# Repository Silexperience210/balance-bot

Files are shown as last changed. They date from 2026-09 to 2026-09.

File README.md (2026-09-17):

<div align="center">

# ₿ B-bot — le robot qui tient debout, en forme de Bitcoin

**ESP32-S3 · deux roues Ø83 mm · servos 360° · écran-visage · châssis imprimé en PETG**







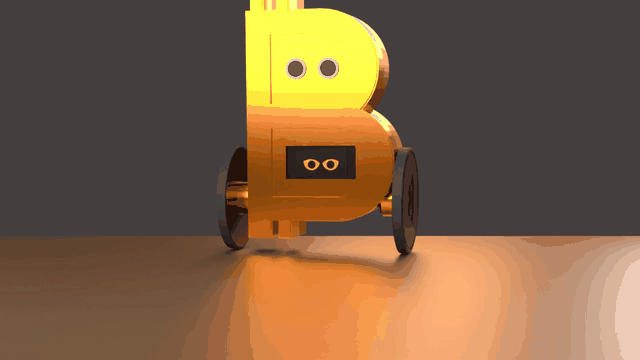
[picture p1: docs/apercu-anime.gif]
Aperçu du B-bot en mouvement


*Rendu du châssis réel — [voir la vidéo complète (26 s)](docs/video-rendu.mp4)*

### [▶ Essayer le simulateur maintenant](https://silexperience210.github.io/balance-bot/simulateur.html)

*Rien à installer : ça tourne dans le navigateur, avec les vrais fichiers STL du châssis.*

📖 **[Guide du simulateur](docs/GUIDE-SIMULATEUR.md)** — les commandes, les scénarios, le
capteur à ultrasons, et comment ajouter tes propres effets au robot (vent, pente, panne de
capteur, tape…).

</div>

---

## Le robot, en vrai

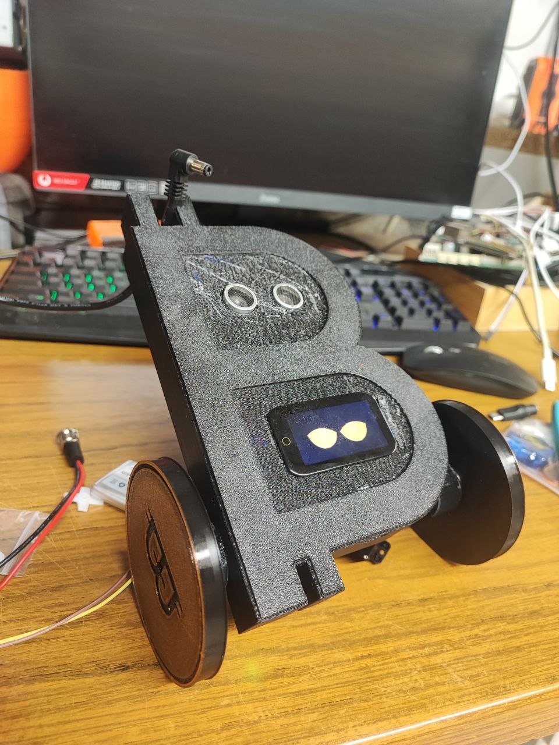
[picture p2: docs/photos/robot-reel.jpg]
Le prototype sur l'établi


Le prototype imprimé en PETG. Le corps **est** le glyphe ₿ ; l'écran couleur lui fait
un visage, les deux capteurs à ultrasons tiennent lieu d'yeux, et les roues sont
chaussées de bandes TPU imprimées.

## L'idée

Un robot auto-équilibré classique tient sur deux roues grâce à un asservissement :
il mesure son inclinaison deux cents fois par seconde et commande ses roues pour
ramener son centre de gravité sous lui, en permanence, y compris à l'arrêt. Ici,
cette mécanique éprouvée porte une coque dessinée comme le symbole Bitcoin, avec un
écran qui lui donne une tête.

Ce dépôt contient **le firmware, le châssis (CAO + STL) et un simulateur** — dont un
simulateur web qui rejoue la même physique que le robot, dans le navigateur.

## Ce qu'il fait

- **Il se tient debout tout seul** — boucle d'équilibre à **200 Hz**, correcteur PID
  sur l'angle du pendule inversé, avec recentrage pour ne pas dériver.
- **Il réagit à ce qu'il voit** — un HC-SR04 scrute devant lui (portée utile 150 cm,
  arrêt d'urgence à 25 cm).
- **Il a un visage** — l'écran ST7789 dessine des yeux dont l'expression suit l'état
  réel du robot (équilibre, chute, batterie faible).
- **Il se règle à chaud** — on se connecte au point d'accès **`BalanceBot-Tune`**
  (http://192.168.4.1/) et on ajuste les gains avec des curseurs, en regardant la
  télémétrie, **sans recompiler**.
- **Il surveille sa batterie** — tension mesurée en continu, seuil bas à 3,5 V (et
  distinction « batterie faible » / « alimenté par USB »).

## Le simulateur

C'est la pièce maîtresse pour qui veut toucher au contrôle sans risquer un robot.

- **`sim/balancebot_sim.py`** — le modèle Python : pendule inversé 1D, **le même
  correcteur que le firmware**, et deux modes physiques (`roue` pour les servos
  360°, `arc` pour l'ancienne mécanique à pieds).
- **`sim/web/`** — le simulateur navigateur : moteur JavaScript **vérifié numéro à
  numéro contre la version Python** (même générateur aléatoire, écart nul sur les
  scénarios sans bruit), rendu **Three.js avec les vrais STL du châssis**, l'écran et
  son visage, un banc de six scénarios et tous les gains réglables au curseur.

### La règle d'or

> **Le simulateur et le firmware doivent dire la même chose.**

Toute divergence entre les deux est traitée comme un bug **du simulateur comme du
firmware** : la physique (rayon de roue, hauteur du centre de gravité, signe des
termes de commande), les butées et les seuils sont alignés des deux côtés. C'est ce
qui permet de régler des gains en simulation avant de risquer le robot — le
simulateur a par exemple écarté un `Ki` vingt fois trop faible qui ne pouvait pas
tenir debout.

## Sous le capot

| Élément | Détail |
|---|---|
| Carte | LilyGo T-Display-S3-Touch (ESP32-S3R8, 16 Mo flash, 8 Mo PSRAM) |
| Capteur d'assiette | MPU6050 (I2C 400 kHz, filtre complémentaire) |
| Écran | ST7789 170×320 (paysage), dalle tactile CST816 |
| Distance | HC-SR04 (broche ECHO avec diviseur de tension) |
| Actionneurs | 2× servos 9 g **à rotation continue** pour les roues (sélecteur 180°/360° à la compilation) |
| Batterie | 1S LiPo, mesure par ADC, seuil bas 3,5 V |
| Boucles | équilibre **200 Hz**, interface 60 Hz, tête/ultrason 50 Hz |
| Châssis | ₿ 132 × 46 × 201 mm, ~378 g (367 g PETG + 11 g TPU), voie 108 mm |

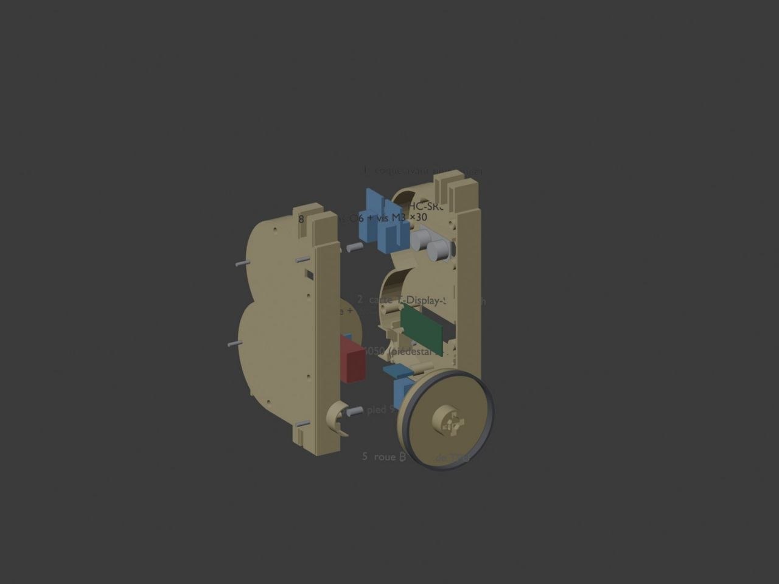
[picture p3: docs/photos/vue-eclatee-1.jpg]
Vue éclatée du châssis


## Physique et réglage

Le robot est un pendule inversé : rayon de roue **R = 41,5 mm** (pneu Ø83), hauteur
du centre de gravité **H = 80 mm**, gravité 9,81 m/s². Les gains embarqués sont
`Kp 25 · Ki 500 · Kd 0,5`, avec une condition de stabilité utile : **Ki > g/R ≈ 300**
(pour un robot d'environ 40 mm de rayon effectif, un terme intégral trop faible ne
rattrape jamais une inclinaison lente).

Le réglage fin se fait au banc web, sans recompiler.

## Le dépôt

```
balance-bot/          FIRMWARE (ce qui tourne sur la carte)
  balance-bot.ino     assemblage + cadences (200 / 60 / 50 Hz)
  config.h            affectations des broches — source unique
  interfaces.h        BotState partagé (contrat entre modules)
  imu.cpp/h           MPU6050, filtre complémentaire, détection de figement
  balance.cpp         correcteur d'équilibre + recentrage
  feet.cpp/h          actionneur des roues (position ou rotation continue)
  head.cpp            tête pan/tilt + télémétrie ultrason
  battery.cpp/h       mesure batterie, seuils, hystérésis
  ui.cpp              écran + écran-visage + boutons
  tuner.cpp/h         banc de réglage web à chaud (AP BalanceBot-Tune)
chassis/              CAO : gen_bitcoin_bot.py, STL (v3/), NOTES_v3.md, rendus
sim/                  simulateur Python (même correcteur que le firmware)
  web/                simulateur navigateur (Three.js + STL réels)
docs/                 visuels, vidéo de présentation et guide du simulateur
scripts/              vérificateur de la règle d'or (simulateur ↔ firmware)
ROADMAP.md            la feuille de route du projet, avec l'état de chaque chantier
TEST_PROTOCOL.md      protocole du premier essai debout (à lire avant d'allumer)
BACKLOG.md            suivi de la campagne d'amélioration
REVIEW_KIMI.md        revue de code indépendante (agent Kimi K3)
REVIEW_CLAUDE.md      contre-revue indépendante (agent Claude Opus)
```

## Méthode

Le firmware a été écrit et durci par **revues croisées d'agents** : une première
revue indépendante, puis une contre-revue chargée de contester la première — les
désaccords ont été tranchés en lisant le code, pas en votant. Elle a produit une
dizaine de corrections réelles (signe d'un terme de commande inversé entre le
simulateur et le firmware, butée logicielle inversée, zone morte qui transformait le
terme intégral en cliquet, garde batterie qui coupait en pleine action sur un seul
échantillon…). Les comptes rendus sont dans le dépôt, avec les correctifs.

## Avertissement

Projet personnel en cours de mise au point. Le firmware est fonctionnel et
compilable, mais les gains et la mécanique évoluent encore : lis `TEST_PROTOCOL.md`
avant la première mise sous tension, et ne pose jamais un robot équipé de servos sur
une table sans surveiller le premier essai.

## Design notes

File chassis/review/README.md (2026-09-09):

# chassis/review — audit & vérification du châssis ₿ BalanceBot v3.1

Outils d'analyse **mesurée** des STL (aucune confiance dans le générateur : on sonde les maillages).
Tous les scripts tournent avec le venv DfAM (`trimesh` + `scipy`) :

```bash
~/.hermes/venvs/dfam/bin/python chassis/review/<script>.py
```

| Fichier | Rôle |
|---|---|
| `RAPPORT_IMPRESSION_v31.md` | Revue d'impression complète (cotes, surplombs, anomalies, optimisations) — état AVANT corrections |
| `audit.py` | Audit topologique : bbox, volume, composantes, boucles ouvertes, non-manifold, surplombs par orientation d'impression |
| `verif_ultime.py` | **Vérification finale 25 points** : arêtes libres = 0, non-manifold = 0, cotes, volumes, paliers G+D, avant-trous M3, alésages goujons, yeux HC-SR04, fenêtre écran, roue, pneu |
| `test_ouverture.py` | Vérifie que les coques sont bien OUVERTES au joint (design CREUX) et non scellées par une peau |
| `faces.py` | Surplombs réels dans l'orientation d'impression : liste les plafonds plats par altitude (ponts vs support) |
| `find_transform.py` | Retrouve la transformation plaque↔pièce par alignement de sommets (sert à valider `chassis/make_plates.py`) |
| `diag_roue.py` | Diagnostic roue : sections, moyeu, jante, gorge de pneu |
| `mesures_baseline.json` | Mesures de référence du 09/09 (avant corrections) — sert de témoin de non-régression |

## Chaîne complète après un changement de châssis

```bash
blender --background --python chassis/gen_bitcoin_bot.py   # régénère chassis/v3/*.stl
python3 chassis/make_plates.py                             # régénère export/v31/*.stl
~/.hermes/venvs/dfam/bin/python chassis/review/verif_ultime.py   # doit afficher 25/25
```

## Repères (état vérifié 09/09/2026)

- b_front 132,13 × 23,02 × 201,00 — 105,8 cm³ (134 g PETG) — watertight, 5 composantes (1 coque + 4 vides d'avant-trous M3)
- b_back 132,13 × 29,00 × 201,00 — 91,5 cm³ (116 g PETG) — watertight, 1 composante
- coin_wheel Ø80 × 21 — 42,6 cm³ (54 g) · coin_tire Ø83 × 7 — 4,4 cm³ (5,6 g TPU)
- Surplombs réels : 6,7 k mm² (front, dont 5,8 k = fond des creux ₿), 1,05 k (back), 0,59 k (roue), 0 (pneu) → **zéro support**
- Réglages : coques 0,28 mm / roue 0,20 / pneu 0,24 · brim 5 mm · lit 70-80 °C · ponts 0,9 / 25 mm/s

## Pièges déjà payés (ne pas les réintroduire)

- **Outil de perçage coplanaire à une face** → voile/bouchon d'épaisseur nulle. Tout alésage doit DÉPASSER
  la face de sortie de 2 mm (c'est ce qui bouchait le palier gauche).
- **Composante reliée seulement par un sommet** = déchet, pas du solide : purger par connectivité d'ARÊTES.
- **Vide interne légitime** (avant-trou borgne) = composante fermée séparée : ce n'est PAS une pièce flottante.
- **Plaques de slicing périmées** : `make_plates.py` après chaque régénération, sinon on slice l'ancien design.
- **Sonder sur l'axe d'un palier donne un vide** (c'est normal) : sonder dans la paroi du tube (y = ±12,8).

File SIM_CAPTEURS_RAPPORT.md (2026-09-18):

# SIM_CAPTEURS_RAPPORT — Capteurs à ultrasons + animations du corps

Date : 2026-09-17. Portée : `sim/web/` + l'emballeur. Le firmware
(`balance-bot/`) et le châssis n'ont **pas** été touchés — ils restent la
référence. Le cœur du moteur `engine.js` n'a **pas** été modifié : le hook
`customEffects` reste la seule porte d'injection de la physique.

## Ce qui a été ajouté, fichier par fichier

### `sim/web/ultrason.js` (NOUVEAU)

Module pur JS (zéro dépendance, exporte `window.Ultrason` + `module.exports`
pour Node), transcription comportementale de `balance-bot/head.cpp`. Il est
cadencé sur l'horloge du moteur : le viewer l'appelle une fois par pas de 5 ms
(200 Hz = `BALANCE_LOOP_HZ`, `config.h:65`), donc les mesures tombent tous les
40 pas — tous les 200 pas après 3 échecs. Chaque comportement, ligne à ligne :

| Comportement simulé | Référence firmware |
|---|---|
| Constantes `US_MAX_CM = 150`, `US_STOP_CM = 25` | `config.h:75-76` |
| Bornes tête pan 0…180°, tilt 20…90°, centre 90°/60° | `config.h:71-74`, `head.cpp:59-62` |
| Vitesse tête 30°/s, position float bornée par pas | `head.cpp:38-39`, `head.cpp:191-195` |
| Cadence adaptative : 200 ms, 1000 ms après 3 échecs consécutifs, retour à 200 ms dès qu'un écho revient | `head.cpp:106-113` |
| Timeout `pulseIn` = `150 × 58 + 800 = 9500 µs` : l'écho « revient » si `dist × 58 ≤ 9500` (soit ≈ 163,8 cm) | `head.cpp:134-135` |
| Conversion `distance = durée_µs / 58` (côté sim : la distance réelle est l'entrée, la durée est le critère d'écho) | `head.cpp:139` |
| Timeout **non injecté** dans la moyenne, distance publiée −1, pas d'alerte | `head.cpp:146-151` |
| Lissage exponentiel sur 5 échantillons (`moy += (mesure − moy) / 5`), amorcé sur la 1re mesure | `head.cpp:26-28`, `head.cpp:155-157` |
| Alerte quand la distance lissée < 25 cm, angle où l'obstacle a été vu | `head.cpp:163-170` |
| Lissée > 150 cm → « hors portée » (`obstacleCm = −1`) **sans** compter un échec | `head.cpp:173-175` |
| Équilibre → tête ramenée au centre, immobile ; au sol → balayage continu | `head.cpp:190-205` |
| `reset()` = `Head::begin()` : lissage et balayage remis à zéro | `head.cpp:84-95` |

Le module ne fait que **publier** `obstacleCm` / `obstacleWarn` / `angleVu` :
comme le firmware, il ne déclenche aucune réaction physique du robot.

### `sim/web/ui.js` (modifié)

- **Garde-fou** : bannière d'erreur si `ultrason.js` est absent (même esprit que
  celui d'`engine.js`).
- **Module HC-SR04 en 3D** : pièce achetée, pas de STL → modélisation
  Three.js : PCB bleu 45 × 20 × 2 mm + deux transducteurs Ø16 × 12 mm avec
  grille avant. UN SEUL module, comme le robot réel (`config.h:61-62` :
  un TRIG, un ECHO ; `docs/photos/robot-reel.jpg`) : centré en Z sur la face
  avant, lobe haut du ₿ (y = +98 mm au-dessus de l'axe), plaqué sur la coque
  (x = 23 mm, face avant mesurée sur `parts.js`). Ajouté à `groupeCorps` →
  il suit exactement les transformations du corps.
- **Mesure analytique** : la distance est calculée depuis la pose PHYSIQUE
  (`sim.state` : x = R·(θ+φ) + SONDE_X·cos θ + SONDE_Y·sin θ), jamais depuis
  le maillage — les animations ne peuvent pas la toucher (voir
  « Après contre-vérification »).
- **Obstacle déplaçable** : plaque verticale de 10 × 140 × 100 mm posée au sol,
  placée par le curseur (5–200 cm). La distance mesurée est recalculée chaque
  frame **depuis la sonde** (`getWorldPosition`) jusqu'à la face avant de
  l'obstacle, dans le plan du sol — pas depuis le centre du robot. Quand le
  robot roule vers l'obstacle, la mesure diminue réellement.
- **Faisceau** : cône semi-transparent apex au capteur, longueur = distance
  réelle bornée à la portée ; vert = obstacle détecté, rouge = ALERTE < 25 cm,
  gris discret = rien/hors portée, masqué si le capteur est débranché.
- **Cadencement** : dans la boucle rAF, après `sim.stepMany(n)`, le viewer
  appelle `us.tickMany(n, distanceReelleCm(), !sim.state.fallen)` — le capteur
  partage l'horloge simulée (mesures aux mêmes instants que sur le robot).
  `us.reset()` est couplé au bouton RESET et au changement de scénario.
- **Télémétrie capteur** : distance lissée, état (rien / obstacle /
  ALERTE < 25 cm / absent), cadence courante (200/1000 ms), échecs consécutifs,
  pan/tilt de la tête, angle vu.
- **Animations** (sélecteur « ANIMATIONS » + bouton « Rejouer ») : `Aucune`,
  `Hochement`, `Regard gauche-droite`, `Sursaut`, `Danse`. Couche strictement
  cosmétique : offsets (tangage, lacet, rebond) ajoutés au **maillage** après
  la pose physique dans `majScene()`, plus expression/regard du visage forcés
  (`visage.exprAnim` / `gazeAnim`). `sim.state` et la commande ne sont jamais
  touchés ; `Aucune` = offsets nuls → image strictement identique à avant.
  Horloge = temps réel rAF (l'animation joue même en pause, sans avancer la
  physique) ; `Sursaut` est un one-shot de 0,7 s relançable, les autres
  bouclent ; changer de sélection ou cliquer « Rejouer » repart de t = 0.

### `sim/web/index.html` (modifié)

- Deux panneaux dans la colonne de droite (style existant conservé) :
  « Capteur ultrason (HC-SR04) » (curseur d'obstacle 5–200 cm, case « ECHO
  câblé », mini-grille de télémétrie) et « Animations » (sélecteur + Rejouer).
- Balise `<script src="ultrason.js"></script>` entre `engine.js` et `parts.js`.
- Styles : `#sel-anim` repris du sélecteur de visage, états du capteur
  colorés via les variables du thème (`--vert`, `--rouge`).

### `sim/web/selfcheck.js` (modifié) + `sim/web/selfcheck.html` (modifié)

- Sections 1–4 **inchangées** (mêmes valeurs de référence Python, mêmes
  tolérances) — la physique n'a pas bougé et l'écart reste nul.
- Nouvelle section 5 (16 contrôles) sur `ultrason.js` : cadence 200 ms
  (mesures à 200/400/600/800/1000 ms), amorçage du lissage, saut 80→30 cm
  (moy = 70 exactement), convergence, cadence 1000 ms après 3 échecs
  (200/400/600/1600/2600 ms), retour à 200 ms à l'écho retrouvé, timeout non
  injecté (44 = 40 + (60−40)/5), portée (160 cm = écho hors portée sans échec,
  170 cm = timeout), alerte < 25 cm + angle vu = 90°, balayage borné 0…180°,
  recentrage 90°/60° en équilibre.
- `selfcheck.html` charge `ultrason.js` avant `selfcheck.js`.

### `chassis/assets/emballer_simulateur.py` (modifié)

`ultrason.js` ajouté à `ORDRE`. Régénéré : `sim/web/simulateur-balancebot.html`
(1 424 548 octets, 6 fichiers inlinés, aucun `<script src=` résiduel) puis
copié sur `simulateur.html` à la racine (la racine était une copie exacte du
bundle, vérifié par `cmp` avant régénération). Vérifié en `file://` sous
Chrome headless : la scène rend, l'auto-test passe dans le navigateur.

## Sortie réelle de `node sim/web/selfcheck.js`

```
BalanceBot — auto-test du moteur engine.js

1. PRNG MT19937 + random.gauss (référence : CPython, random.seed(42))
  ✔ random() → 0.6394267984578837, 0.025010755222666936
  ✔ gauss(0,1) → -0.14409032957792836, -0.1729036003315193

2. Gains embarqués Kp25/Ki500/Kd0.5, k_out=1, kv=3, cascade ON, graine 42
    θ0=2° propre    : ❌ chute θ  t=0.545 s  θfin=+45.920°  φfin=+23.445°   = Python
    θ0=2° bruit     : ❌ chute θ  t=0.545 s  θfin=+45.919°  φfin=+23.603°   = Python
    θ0=5° bruit     : ❌ chute θ  t=0.425 s  θfin=+46.609°  φfin=+25.944°   = Python
    tape 0.4 rad/s  : ❌ chute θ  t=0.485 s  θfin=+45.009°  φfin=+22.888°   = Python
    tape 0.8 rad/s  : ❌ chute θ  t=0.490 s  θfin=+46.071°  φfin=+24.034°   = Python
    tape 1.2 rad/s  : ❌ chute θ  t=0.485 s  θfin=+45.347°  φfin=+22.690°   = Python
  ✔ 0/6 scénarios tenus (obtenu 0/6)
  ✔ verdicts, instants et états finaux conformes au Python

3. Kp25/Ki350/Kd1, k_out=3, kv=0, cascade ON, graine 42
  ✔ θ0=2° propre → « ok », θ fin = +0.0000° (< 0,5°), φ fin = +7.96°
    θ0=2° propre    : OK         t=5.995 s  θfin=+0.000°  φfin=+7.959°   = Python
    θ0=2° bruit     : OK         t=5.995 s  θfin=-0.038°  φfin=-2.602°   = Python
    θ0=5° bruit     : OK         t=5.995 s  θfin=-0.071°  φfin=+174.429°   = Python
    tape 0.4 rad/s  : OK         t=7.995 s  θfin=+0.001°  φfin=+423.887°   = Python
    tape 0.8 rad/s  : OK         t=7.995 s  θfin=+0.076°  φfin=+829.829°   = Python
    tape 1.2 rad/s  : ❌ chute θ  t=3.585 s  θfin=+45.704°  φfin=+152.366°   = Python
  ✔ 5/6 scénarios tenus comme le Python (obtenu 5/6)
  ✔ verdicts, instants et états finaux conformes au Python

4. Hook setCustom(fn) : appelé après la physique, une fois par pas
  ✔ 100 pas → 100 appels, t = 0.495 s, dt = 0.005
  ✔ state.theta = 60° écrit par le hook à t = 1 s → « chute θ » au même pas

5. Capteur HC-SR04 (ultrason.js) — cadence, lissage, portée, alerte, tête
  ✔ cadence 200 ms : mesures à 200, 400, 600, 800, 1000 ms
  ✔ lissage amorcé sur la 1re mesure : obstacleCm = 80 cm exactement
  ✔ saut 80→30 cm : une mesure après, moy = 70.00 (attendu 70)
  ✔ la moyenne glissante converge vers la distance réelle (30.000571 → 30, ±0,01 cm)
  ✔ capteur débranché : cadence 1000 ms après 3 échecs (200, 400, 600, 1600, 2600 ms)
  ✔ débranché : cadence affichée 1000 ms, distance invalide, pas d'alerte
  ✔ écho de retour → cadence 200 ms immédiate, moyenne re-amorcée à 50
  ✔ timeout : distance invalide publiée, pas d'alerte
  ✔ timeout non injecté : moyenne reprise en l'état (44.00 = 40 + (60−40)/5)
  ✔ 160 cm : écho reçu mais hors portée (obstacleCm = −1, pas d'échec)
  ✔ 170 cm : au-delà du timeout pulseIn (9860 > 9500 µs) → échec compté
  ✔ 20 cm lissés → ALERTE, angle vu = pan 90° (tête centrée)
  ✔ obstacle reparti → alerte et angle effacés
  ✔ balayage hors équilibre : pan borné à 0…180° (vu 0…180)
  ✔ équilibre : tête ramenée au centre (90°/60°) et immobile

═══ AUTO-TEST RÉUSSI ═══
```

(code de sortie 0 ; même verdict « AUTO-TEST RÉUSSI » sous Chrome headless en
ouvrant `sim/web/selfcheck.html` en `file://`.)

## Ce qui reste imparfait

- **Le balayage de tête n'est pas visible en 3D** : le châssis n'a pas de
  maillage de tête séparé (la « tête » est le corps entier), donc pan/tilt ne
  sont simulés que logiquement — affichés dans la télémétrie et utilisés pour
  l'« angle vu ». Faire pivoter le corps entier serait faux physiquement.
- **Après la chute, le temps simulé s'arrête** (le moteur s'arrête au verdict,
  comportement d'origine inchangé) : le balayage « robot au sol » n'est donc
  observable en pratique que dans l'auto-test, pas dans la scène live.
- **Distance mesurée dans le plan du sol** (distance horizontale sonde → face
  avant de l'obstacle) : on ignore la différence de hauteur, légitime pour un
  obstacle vertical, mais un obstacle très bas ou très haut ne serait pas
  distingué. L'obstacle est unique, vertical, et ne peut pas être déplacé
  latéralement (curseur de distance uniquement, pas de glisser 3D).
- **La distance est figée pendant chaque lot** de pas calculés entre deux
  frames (échantillonnée une fois par frame) : invisible, car le capteur
  n'échantillonne qu'au plus tous les 40 pas (200 ms).
- **Un seul capteur, logique ET visuel** (comme le firmware et le robot
  réel, `config.h:61-62` + photo) : un seul module HC-SR04 modélisé, la
  mesure part de la face avant de ses transducteurs.
- Le blocage de `pulseIn` (jusqu'à 9,5 ms volés à la boucle d'équilibre) n'est
  **pas** répercuté sur la physique — ce serait modifier le moteur, interdit
  par la mission ; seule la cadence des mesures est reproduite.

## Fichiers modifiés

- `sim/web/ultrason.js` — **nouveau** (capteur HC-SR04 + tête, miroir de `head.cpp`)
- `sim/web/ui.js` — module 3D, mesure analytique, faisceau, obstacle, animations, télémétrie capteur
- `sim/web/index.html` — panneaux « Capteur ultrason » et « Animations », script `ultrason.js`
- `sim/web/selfcheck.js` — section 5 (16 contrôles ultrason/tête), sections 1–4 inchangées
- `sim/web/selfcheck.html` — chargement d'`ultrason.js`
- `chassis/assets/emballer_simulateur.py` — `ultrason.js` ajouté à l'ordre d'inlining
- `sim/web/simulateur-balancebot.html` — régénéré (bundle mono-fichier)
- `simulateur.html` (racine) — copie du bundle régénéré

---

## Après contre-vérification (rapport indépendant `/home/silex/REVIEW_SIM_CAPTEURS.md`, HEAD `4796227`)

La contre-vérification a validé l'essentiel et relevé un défaut bloquant
(point C : les animations faussaient la mesure) plus des finitions. Tous les
points sont traités, dans `sim/web/` + `docs/GUIDE-SIMULATEUR.md` uniquement ;
`engine.js` et la physique d'`ultrason.js` n'ont pas bougé (seul le critère
d'écho du point F-b est corrigé, voir ci-dessous).

**1. (BLOQUANT, défaut C) La distance ne dépend plus des animations.**
Avant : la sonde était un `Object3D` enfant de `groupeCorps`, donc
`distanceReelleCm()` (via `getWorldPosition()`) incluait les offsets
d'animation appliqués par `majScene()`. Correction choisie : la distance est
calculée **analytiquement depuis la pose physique** (`sim.state`), sans passer
par la scène :

```
x_sonde = R·(θ+φ) + SONDE_X·cos θ + SONDE_Y·sin θ     (z = 0)
```

C'est la garantie la plus forte : les offsets d'animation n'existant que dans
le maillage, une mesure qui ne lit pas le maillage ne peut pas les voir — par
construction, pas par convention. Le **faisceau reste enfant de
`groupeCorps`** (il suit visuellement le corps, animations comprises : c'est
le choix assumé, il n'est qu'un pointeur), mais sa **longueur** vient de la
distance physique. Vérifié **par la mesure** (banc Node/Playwright dans
`/tmp/bench`, Chrome, même méthode que le rapport — pause, curseur 18 cm,
θ = 2°) :

| | anim « aucune » | hochement | regard | sursaut | danse |
|---|---|---|---|---|---|
| **avant** (HEAD) | 13,215 cm | 12,56–13,90 (Δ 1,34) | 13,22–13,42 (Δ 0,21) | 13,22–14,07 (Δ 0,86) | 12,87–13,88 (Δ 1,01) |
| **après** | 13,215 cm | **13,215 cm fixe (Δ 0,000)** | idem | idem | idem |

En RUN (« θ0=2° propre », curseur 18 cm) : lissée 13,126 cm sans animation ;
après 3 s de « danse » : **13,124 cm** après correction (13,281 cm avant,
fluctuante). La valeur de référence 13,215 cm est strictement identique avant
et après : la formule analytique retombe sur la pose monde mesurée (sonde
x = 42,85 mm).

**2. (BLOQUANT, F-5) Un seul module HC-SR04.** Le robot réel n'a qu'un module
(`config.h:61-62` ; sur la photo ce sont ses deux transducteurs qui font les
« yeux »). La scène 3D n'en modélise plus qu'**un**, centré en Z (z = 0) à la
place des yeux de la photo : face avant x = 23 mm, lobe haut y = +98 mm,
au-dessus de l'écran. Logique inchangée (un seul capteur, comme le firmware).

**3. (E) Panneau « Obstacle » clarifié.** Ajout d'une ligne d'aide dans le
panneau : le curseur place le **centre d'une plaque de 10 mm mesuré depuis
l'axe des roues au RESET** (si le robot roule, la mesure s'en écarte), et en
**PAUSE** la télémétrie est figée (le capteur ne tique qu'en marche) alors que
le faisceau suit le curseur.

**4. (F-b) Seuil d'écho réel ≈ 155 cm — reproduit, pas seulement documenté.**
Dans le core ESP32, le timeout de `pulseIn` court depuis l'appel, attente du
front montant d'ECHO incluse (~450–500 µs après TRIG — à quoi sert la marge
de 800 µs du firmware). `ultrason.js` modélise désormais ce délai
(`ECHO_DELAI_FRONT_US = 480`, milieu de la plage) : l'écho revient si
`dist×58 + 480 ≤ 9500 µs`, soit un seuil à **155,5 cm** comme le vrai robot.
Le selfcheck borne le seuil : 155 cm = écho hors portée sans échec, 156 cm =
échec compté.

**5. (F-f) Trous de l'auto-test comblés** (section 5 : 16 → 20 contrôles) :
vitesse de pan mesurée (90 → 120° en 1 s de balayage), vitesse de tilt
(60 → 75° en 0,5 s), bornes du tilt en balayage (20…90°), `angleVu` testé à
un pan ≠ 90° (alerte pendant le balayage → 96°, pas le centre). Contre-épreuve
par mutation : `PAN_SPEED 30→60` ✘ détecté (2 contrôles), `HEAD_TILT_MIN 20→0`
✘ détecté, `ECHO_DELAI_FRONT_US 480→0` ✘ détecté.

**6. Libellé** : « moyenne re-amorcée à 50 » → « moyenne amorcée à 50 (premier
écho reçu) » — le capteur n'avait jamais reçu d'écho dans ce scénario.

**7. Commentaire du faisceau** : le « demi-angle ~7° » était faux
(`ConeGeometry(0.0122, 1)` = 0,7° à 1 m, et seul `scale.x` varie). Le
commentaire dit désormais la vérité : rayon constant 12,2 mm, demi-angle
apparent dépendant de la longueur — un pointeur visuel, pas le lobe réel
(~15°) du HC-SR04.

**8. Pas de collision** : écrit dans `docs/GUIDE-SIMULATEUR.md` §8 (« Ce que le
simulateur ne fait pas ») — le robot peut traverser l'obstacle, comme le
firmware qui ne réagit pas.

**Validation finale** : bundle régénéré (`emballer_simulateur.py` →
`sim/web/simulateur-balancebot.html`, 1 426 820 octets, 6 fichiers inlinés,
0 `<script src=` résiduel) et copié sur `simulateur.html` à la racine
(`cmp` identique). `node sim/web/selfcheck.js` → exit 0, sections 1–4
inchangées, section 5 (extraits) :

```
  ✔ 155 cm : écho reçu mais hors portée (obstacleCm = −1, pas d'échec)
  ✔ 156 cm : au-delà du seuil réel (9528 > 9500 µs) → échec compté
  ✔ 170 cm : au-delà du timeout pulseIn (10340 > 9500 µs) → échec compté
  ✔ balayage hors équilibre : tilt borné à 20…90° (vu 20…90)
  ✔ vitesse de pan 30°/s : 90 → 120° après 1 s de balayage (attendu 120)
  ✔ vitesse de tilt 30°/s : 60 → 75° après 0,5 s de balayage (attendu 75)
  ✔ alerte pendant le balayage : angle vu = pan courant (96°, ≠ 90°)
═══ AUTO-TEST RÉUSSI ═══
```

(même verdict « AUTO-TEST RÉUSSI » sous Chrome headless en `file://` ; rendu
du bundle vérifié par capture : un seul module à deux transducteurs au-dessus
de l'écran, comme la photo.)

---

**Post-scriptum (miroir du firmware `10044c0`, 18/09/2026)** — ce rapport décrit l'état
au commit `2911095` : les numéros de lignes de `head.cpp` cités ci-dessus sont ceux d'AVANT
`10044c0` (décalés d'environ +100 depuis : `kEchoTimeoutUs` l.134 → 232, cadence l.108 →
203, `handleHeadMovement` l.181-217 → 284-333), et les deux phrases « équilibre → tête
ramenée au centre, immobile » et « comme le firmware, il ne déclenche aucune réaction
physique » ne sont plus vraies : la tête balaie ±30° en équilibre et le firmware évite
l'obstacle (ralenti / recul + pivot / reprise). Le simulateur en est le miroir — voir
`SIM_MIROIR_RAPPORT.md`, `docs/GUIDE-SIMULATEUR.md` §5 bis et `sim/web/selfcheck.js` §6-8.

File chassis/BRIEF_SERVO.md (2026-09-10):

# Brief — Baies de servo du châssis BalanceBot v3 (à corriger)

## Contexte
Le châssis est **généré paramétriquement** par `chassis/gen_bitcoin_bot.py`
(script Blender). Ne modifie QUE ce fichier et les STL régénérés.

Les 2 servos de roue sont des **SG90** : corps 22,8 × 12,2 × 22,5, **arbre de
sortie à 5,9 mm du fond** du corps, bossage de sortie Ø11,8 × 1,5, **oreilles de
fixation 32,2 de long**, sortie de câble sur un flanc, et de petits **taquets de
moulage** en saillie.

Constantes du générateur (déjà dans le fichier) :
`SV_L=22.8`, `SV_W=12.2`, `SV_H=22.5`, `SV_SHAFT_OFF=5.9`, `SV_BOSS_D=11.8`,
`SV_BOSS_H=1.5`, `SV_PILOT_D`, `HUB_BORE_D=SV_SHAFT_D+0.4`, `WALL=2.4`,
`AXLE_Z=42.0`, `GW=118`.

Implantation prévue par le code (repère NON miroir) :
- servo couché, **axe selon X**, sortant par les parois latérales à `z = AXLE_Z` ;
- corps entre `z = AXLE_Z - SV_SHAFT_OFF` et `z + SV_L` (soit 36,1 → 58,9) ;
- cavité ouverte depuis `x = WALL` (côté spine) et depuis
  `x = x_wall_R - WALL` (côté paroi courbe), corps s'étendant vers l'intérieur ;
- l'arbre + le bossage traversent la paroi par un trou Ø12,8 (`axR`/`axL`) et
  entrent dans le **moyeu Ø24 de la roue** ; le moyeu tourne dans le
  **tube-palier Ø24,5** extérieur ;
- les oreilles se vissent (M2 × 8, avant-trous Ø1,7) sur les **cloisons
  verticales (bulk) — cloisons à x = 12…23 et 68…79** (repère non miroir).

## Problème constaté sur la pièce réellement imprimée
1. **Le servo ne rentre pas.** Il possède un **taquet** (saillie de moulage) et
   ses oreilles de fixation ; la cavité est au plus juste → il faut **~1 mm de
   jeu en plus** sur les faces concernées.
2. **Côté opposé, un PLOT DE FIXATION tombe en plein milieu de l'emplacement du
   servo** et le bloque. (Vérifier aussi la cloison `bulk` : une cloison de 11 mm
   d'épaisseur tombe dans l'emprise du corps du servo.)

## Travail demandé

### 1. Trouver un VRAI modèle de SG90
Télécharge un modèle **STL ou STEP d'un SG90 réel** (GrabCAD, Printables,
Thingiverse, ou un dépôt de modèles CAO fiable). Vérifie sa provenance et que
ses cotes correspondent : corps 22,8 × 12,2 × 22,5, oreilles 32,2 × 12,2,
bossage Ø~11,8, arbre Ø4,8, **taquets et sortie de câble présents**. Si aucun
modèle correct n'existe, reconstruis un solide fidèle à partir d'un **datasheet
officiel** (TowerPro SG90 : drawing coté) et dis-le explicitement dans le
rapport.

### 2. Vérifier l'emplacement par la géométrie (pas à l'œil)
Dans Blender (headless) : importe les coques `b_front`/`b_back` régénérées et le
modèle de servo, place le servo **exactement** comme le prévoit le générateur,
puis mesure l'**intersection booléenne** servo × coques. Elle doit être **0 mm³**.
Liste chaque zone de collision avec ses cotes (x, y, z) et l'épaisseur à
enlever. Vérifie aussi qu'il reste **~1 mm de jeu** partout et qu'un **doigt de
montage** peut atteindre les oreilles.

### 3. Corriger `build_body()`
- élargir la cavité d'**au moins 1 mm** là où le taquet/les oreilles coincent ;
- **supprimer ou déplacer** le plot de fixation qui tombe dans l'emprise du servo
  (s'il sert à visser autre chose, déplace-le hors de l'emprise, ne le supprime
  pas à l'aveugle) ;
- dégager la sortie du câble et l'accès aux vis d'oreilles ;
- **NE PAS** toucher à l'enveloppe extérieure, à `AXLE_Z`, aux trous Ø12,8, aux
  tubes-paliers Ø24,5, ni à la poche de la carte / la fenêtre de la dalle.

### 4. Régénérer et prouver
- régénère les STL (comme `chassis/run_v3_design.sh` le fait) ;
- `python3 chassis/verif_ultime.py` doit rester **25/25** (watertight, 0 arête
  libre, 0 non-manifold, cotes de l'enveloppe inchangées) ;
- intersection servo/coques = **0 mm³** (re-mesure après correction) ;
- pas de nouveau surplomb critique pour l'impression.

### 5. Rapport final (court, chiffré)
Avant/après : cotes de la cavité modifiée, zone du plot déplacé, volume
d'intersection (avant → après), source et cotes du modèle de servo utilisé,
résultat de `verif_ultime.py`. Signale tout ce que tu n'as pas pu vérifier.

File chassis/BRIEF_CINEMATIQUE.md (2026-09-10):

# Brief — Cinématique BalanceBot : tout disparaît pendant l'éclaté

## Symptôme (constaté par l'utilisateur, confirmé par mesure)
Dans `chassis/render/cinematique.mp4`, **au moment de la vue éclatée, plus rien
n'est visible** : le cadre est vide et les pièces ont disparu. Le reste de la
vidéo est bon.

Mesures sur les images rendues (`chassis/render/frames/f_%04d.png`, 1280×720),
comptage des pixels « orange métal » (r>90, r>1.5g, g>1.3b) :

| image | phase | pixels orange | image occupée |
|---|---|---|---|
| 300 | orbite (OK) | 30 339 (x 468..807) | normal |
| 390 | début éclaté | 917 (x 303..363) | ça rétrécit |
| **421** | **pic de l'éclaté** | **333 (x 287..303, y 691..719)** | **1,6 % — cadre vide à 95-98 %** |
| 480 | remontage | 8 599 (x 378..467) | ça revient |

À l'image 420, un modèle de vision ne voit qu'**un petit objet cylindrique noir
(<1 % de l'image)**, décentré en bas à droite. Les coques orange (132 × 201 mm)
devraient pourtant occuper ~13 % du cadre à 1 000 mm avec l'objectif de 62 mm :
elles ne sont plus dans le champ.

## Code concerné (`chassis/assets/cinematique.py`)
- **Caméra** : bloc `CAM_KEYS` (à partir de « caméra : gros plan sur l'écran »).
  L'azimut vient de la rotation Z de l'empty `orbite` ; `placer_camera(0, dist,
  haut, cible)` ne pose que la position LOCALE et la visée.
- **Éclatement** : dict `ECLATE` + la boucle
  `pieces = {... if o.name in ECLATE}` → clés `(1, pos_a)`, `(240, pos_a)`,
  `(420, pos_e)`, `(570, pos_a)`.
- Les pièces éclatées sont parentées au `pivot` (empty sur l'axe des roues) avec
  `matrix_parent_inverse`.

## Suspicions à vérifier (ne pas se contenter de la première)
1. **La ROTATION de la caméra n'est jamais keyframée** — seule `location` l'est.
   La visée reste donc celle de la DERNIÈRE entrée de `CAM_KEYS` (image 780 :
   200 mm, haut 84, cible 76) alors que la caméra se balade de 115 à 1120 mm.
   Calcule l'écart de visée réel et son effet.
2. Interpolation Bézier des positions : vérifier qu'aucune clé n'overshoot (la
   caméra pourrait partir très loin entre deux clés).
3. Les vecteurs d'éclatement sont additionnés à `obj.location` : pour les coques
   importées (STL) `location` vaut (0,0,0) et la géométrie porte les cotes —
   vérifier que le décalage appliqué est bien celui attendu.
4. Vérifier enfin que rien ne masque : ordre le long de l'axe de visée.

## Travail demandé
1. **Diagnostiquer la cause RÉELLE** avec un **script de projection** :
   `bpy_extras.object_utils.world_to_camera_view` + `scene.frame_set(f)` **puis
   `bpy.context.view_layer.update()`** (sans ce refresh les matrices restent
   figées et la mesure est fausse — piège déjà rencontré). ATTENTION : les clés
   de caméra sont dans le bloc « mode cinématique », APRÈS la ligne
   `if MODE == "still":` → un probe qui n'exécute que l'en-tête du script n'aura
   AUCUNE animation de caméra. Construis le probe de façon à évaluer la scène
   animée complète.
   Pour chaque pièce et chaque image clé (300 / 390 / 420 / 480 / 570), imprime
   la position caméra monde, la boîte englobante en pixels et si elle est dans le
   cadre (0..1280 × 0..720).
2. **Corriger** ce qui est faux (viser correctement à chaque image — keyframer la
   visée si nécessaire — et adapter les distances/offsets pour que TOUTES les
   pièces restent dans le cadre avec une taille lisible pendant l'éclaté).
3. **Prouver** : re-rendre SEULEMENT quelques images de contrôle, pas les 780 :
   `blender --background --python chassis/assets/cinematique.py -- cine 390 430`
   (le script accepte déjà une plage `[début fin]`). Puis, sur ces images,
   **recompter les pixels orange** et vérifier que les coques ET les composants
   (carte, dalle, servos, capteurs) sont visibles et bien cadrés. Donne les
   chiffres avant/après.
4. Ne pas toucher : durée (26 s), 30 fps, 780 images, 1280×720, ni le châssis
   (`chassis/gen_bitcoin_bot.py`, les STL, le travail servos déjà commité).

## Rapport attendu
Cause racine (une phrase), ce qui a été changé (chiffres), les mesures de pixels
avant/après sur les images de contrôle, et ce que tu n'as PAS pu vérifier.

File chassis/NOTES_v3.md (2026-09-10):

# ₿ BalanceBot v3 — NOTES DE CONCEPTION (châssis symbole Bitcoin)

## Pièces (dans chassis/v3/) — cotes MESURÉES (09/09/2026)
| Fichier | Rôle | Dimensions (bbox mm) | Masse PETG (100 %) |
|---|---|---|---|
| b_front.stl | Coque avant (face ₿, écran, yeux) | 132,1 × 23,0 × 201,0 | 134 g |
| b_back.stl | Coque arrière (élec., goujons) | 132,1 × 29,0 × 201,0 | 116 g |
| coin_wheel.stl ×2 | Roues-pièces ₿ Ø80 × 10 + moyeu Ø24×13 | Ø80 × 21 | 54 g |
| coin_tire.stl ×2 | Bandes TPU (TPU 95A) | Ø83 × 7 | 5,6 g TPU |

Total ≈ 378 g (367 g PETG + 11 g TPU). Corps : glyphe ₿ 118 × 165 (GW × GH) + barres → 201 de haut,
profondeur 46 (23 + 23) + goujons 6. Voie des roues (plans médians) : ≈ 108 mm.
**Coques CREUSES** (pas de peau au joint) : la cavité s'ouvre sur le plan de joint y=0, le hardware
se monte par l'ouverture avant vissage (4 goujons + 4 vis M3).

## Montage
1. Servos 9 g continus (SG90-FS90R size) TÊTE EN BAS, collés à leur paroi : face de sortie contre la paroi
   latérale intérieure (gauche : spine x=90 ; droite : paroi courbe x≈11), corps dans la cavité, pattes
   vissées (M2 × 8, Ø1.7) sur les cloisons verticales (bulk) — cloisons à x = 12…23 et 68…79.
2. L'axe/bossage du servo traverse la paroi par un trou Ø12.8 (axR/axL) puis entre dans le moyeu Ø24 de la roue.
3. Roue : enfiler le moyeu sur le palonnier (croix) pré-vissé à l'axe ; le moyeu (13 mm) coulisse dans le
   tube-palier du corps (Ø24.5) ; l'empreinte au fond du moyeu (3.6 mm) attrape la croix. Jeu axial ~3 mm
   (lamage HUB_CB_H+3) pour ne pas serrer.
4. Bande TPU : étirer par-dessus la jante (gorge Ø69 × 8.4, bande Ø int 68.1 → interférence 0.9).
5. Joint des coques : goujons Ø5.8 (b_back, x4) → alésages Ø6.0 (b_front, prof 6.8) ; vis M3 × 30
   tête noyée Ø6.4 (b_back) → passage Ø3.4 → avant-trou Ø2.6 dans les plots du front (autotaraudage).
   Plots de vis à 4 endroits : spine z≈71/142, mur courbe bas droite (45°), plafond panse haute (z≈184).
6. Carte T-Display S3 : paysage, dalle dans la fenêtre 56 × 26 du contre-poinçon bas (lcz≈72 ; demande
   utilisateur du 10/09 : l'ouverture de 40,6 × 22,6 ne laissait pas passer la dalle + son encadrement) ;
   rails haut/bas + 2 vis M2 aux trous réels (x = lcx − 30.39 + 57.66, z = lcz ± 10) ; USB-C vers le bas
   (lumière sous le corps à z=19-23).
7. MPU6050 : piédestal dont le DESSUS est à z = 36.5 (l'axe de tangage !) ; vis M2 entraxe 15 (Ø1.7).
8. HC-SR04 : poussé dans la baie haute (fenêtre 45×20), transducteurs dans les 2 trous Ø16.6 (entraxe 26) ;
   colle sur les rails.
9. Interrupteur : lumière 13 × 8 côté arrière du spine (z 148-156).

## Orientation d'impression (P1S, plateau 256 × 256)
- b_front / b_back : face externe sur le plateau (creux vers le haut). Le creux COUNTER de la face ₿
  n'est PAS imprimé en l'air (la face externe EST le plateau) ; les 2 panse-creux (5 831 mm² à 1,6 mm)
  se pontent. Goujons/plots vers le haut. Hauteur d'impression 23 (front) / 29 (back) → ça rentre large.
- coin_wheel : face externe (₿ gravé) sur le plateau → la gravure sort en relief (creux du moule) ;
  moyeu vers le haut. PETG.
- coin_tire : à plat (anneau). TPU 95A.
- **Plaques de slicing** : `export/v31/plate1_b_front.stl` (201 × 132 au sol), `plate2_b_back.stl`,
  `plateR_wheel1/2.stl`, `plateT_tire1/2.stl`. **À RÉGÉNÉRER après tout changement** :
  `python3 chassis/make_plates.py` (transformations vérifiées : 100 % des sommets alignés).
  Les plaques de 14h44 du 08/09 étaient périmées (version FERMÉE + alésage de palier bouché).
- Le CLI headless refuse les coques > ~195 mm (dimension 201) → **slicer en GUI Bambu Studio**.

## Réglages de slicing recommandés (P1S, PETG 0,4 mm)
| Réglage | Coques (front/back) | Roue | Pneu |
|---|---|---|---|
| Hauteur de couche | **0,28** (−30 % de temps) | 0,20 (gravure ₿) | 0,24 |
| Parois | 6 (épaisseur 2,4 mm = la pièce) | 4 | 3 |
| Remplissage | n/a (parois pleines) | 20 % gyroid | 15 % gyroid |
| Support | **aucun** (ponts internes) | aucun | aucun |
| Adhérence | bordure (brim) 5 mm, lit 70-80 °C | brim 5 mm | brim 5 mm |
| Ponts | débit 0,9 · 25 mm/s · ventilo 100 % | idem | — |
| Divers | 1re couche 0,24 · « éviter de traverser les parois » | — | vitesse TPU 25 mm/s |

Surplombs réels mesurés (hors faces posées sur le plateau) : 6,7 k mm² (front, dont 5,8 k = fond des
creux ₿ à 1,6 mm), 1,05 k mm² (back), 0,59 k mm² (roue), 0 (pneu) → aucun support nécessaire.

## Révision du 09/09/2026 (revue impression + corrections)
1. **Alésages de palier bouchés** : le fond de l'alésage tombait pile sur le bout du tube → voile
   d'épaisseur nulle / bouchon plein dans le tube GAUCHE (moyeu impossible à enfoncer). Les alésages
   dépassent maintenant le bout des tubes de 2 mm (bearR → x_in_R+2,5 ; bearL → −14,0).
2. **Purge automatique des voiles** : `purger_dechets()` supprime toute composante à épaisseur nulle
   (connectivité par arêtes) après `nettoyer()` — plus de plaques fantômes (le back passe de 3 composantes
   à 1, watertight, profondeur réelle 29 au lieu de 34,9 gonflée par un voile flottant).
3. **Plaques de slicing régénérées** (`chassis/make_plates.py`) depuis les STL courants.
4. **Avant-trous M3** : présents en vides internes Ø2,6 × 16 mm dans les 4 plots (autotaraudage).
5. **Non-manifold** : les compteurs bruts des STL (39/102/1927/585) sont des sommets non soudés —
   après `merge_vertices` les coques sont watertight (back) ou fermées hors ouverture de joint (front).

## Révision du 10/09/2026 (baies de servo — le SG90 n'entrait pas)

Vérification par **intersection booléenne EXACTE** servo × coques
(`review/servo_fit.py`, modèle `review/sg90_model.py`) : **1779 mm³ → 0 mm³**.

| # | Défaut mesuré | Correction |
|---|---|---|
| 1 | La cloison `bulk` occupait **exactement** le volume des oreilles (x_face + d·[4,1 ; 6,6], recouvrement 2,5 / 2,5 mm) : le servo butait dessus. 441 mm³. | Cloison déplacée **en amont** des oreilles, soudée à la paroi latérale : x_face − d·0,6 → x_face + d·4,1 (4,1 mm d'épaisseur). |
| 2 | La boîte `bulk` n'était pas limitée à la cavité → **bosse hors peau** sous l'axe côté panse (matière jusqu'à r = 50,1 pour une peau à r = 46 ; 86 points sondés). | `INTERSECT` avec le glyphe réduit de `WALL−0,6` : la cloison s'arrête 1,8 mm sous la peau. 0 point hors peau. |
| 3 | Le goujon bas du spine (`pins[0]`, z = 38) tombait **en plein milieu** de la baie du servo spine : plot Ø9 en x 5,5…14,5 / z 33,5…42,5, à travers le corps ET les oreilles. | Descendu à **z = 20** (plot z 15,5…24,5, soit 5,9 mm sous l'oreille basse). Écartement des goujons 141 → 159 mm. |
| 4 | Fenêtre servo au `SLIDING_FIT` (0,15/face) : trop juste pour les **taquets de moulage** et la bavure de joint du SG90 réel. | Nouvelle constante **`SV_CLR = 1,0`** mm/face. Premier contact mesuré à 1,05 mm. |
| 5 | Rainure arrêtée à la cloison : la paroi courbe de la panse rentre jusqu'à x = 95,3 sous l'axe → 802 mm³ dans le corps du servo. | Rainure sur **toute la profondeur** du servo (x_face → x_face + d·23,1) + nouveau logement d'oreilles `svear` (SV_FLANGE_T + SV_CLR de profondeur, sur l'envergure 32,2 + 2·SV_CLR). |
| 6 | Vis d'oreilles **inaccessibles** : les oreilles étaient côté paroi, tête de vis dans un espace mort de 4,1 mm. | Oreilles côté cavité ; avant-trous Ø1,7 **borgnes** percés depuis la cavité, arrêtés 0,4 mm avant la paroi (3,7 mm de prise). Dégagement mesuré : **59,5 / 59,5 / 20,5 mm**. Vis : celles **livrées avec le SG90** (≈ Ø1,9 × 6,5) ou **M2 × 6** — plus M2 × 8 (débouchait sur la peau). |
| 7 | `pcbplot` bas (Ø5, x 83,7…88,7, z 59,5…64,5) traversait toute la cavité : 0,6 mm au-dessus du corps du servo panse et **pile devant la sortie de câble**. | Plots raccourcis à y ≥ 8,0 (au-delà de ±7,1 = largeur servo + jeu). Toujours tenus par `pcbrib` → rail → parois. |
| 8 | Piédestal MPU à x = 26,0 pour un servo dont le fond est à x = 24,9 : 1,1 mm. | `MPU_X` 38,0 → **39,0** (2,1 mm). |

**Limites connues, non corrigées** (voir §« à confirmer » du rapport) :
- Côté **panse**, l'oreille BASSE du servo (z ≈ 31…36) tombe **hors de la peau** de la panse
  (le cercle de la panse redescend à r = 46 : la matière s'arrête à x ≈ 100,1 à z = 36,1).
  → **3 vis d'oreille sur 4** seulement (2 spine + 1 panse haute). Le servo est en outre bloqué en
  rotation par la rainure de cloison et pincé par les 2 coques. Corriger demanderait de toucher
  l'enveloppe extérieure (interdit par le cahier des charges) ou de coucher le servo (oreilles selon Y).
- Le **capot oblong** relevé sur la CAO de référence (Ø11,8 débordant de 2,9 mm vers le bout long,
  4 mm de haut) n'est **pas** au datasheet et n'est pas dégagé : 269 mm³ d'intersection si le servo
  réel le présente. Le débouchage demanderait d'ovaliser `axR`/`axL` (interdit : trous Ø12,8 gelés).

## Réglages électriques (rappel POWER_GUIDE)
- Servos sur 5 V séparé (BEC/buck), GND commun ; jamais le 3V3 de la carte.
- Firmware : mode FEET_MODE_CONTINUOUS (déjà prêt, Lot 3a) ; constante kAccelPitchSign à vérifier au test.

## Historique de conception (bref)
- v3.0 glyphe paramétrique (spine/panses/barres) ; coque 2 moitiés à joint y=0 ; contre-poinçons lus par ombres.
- Instabilités booléennes EXACT combattues : alésages des paliers limités AU TUBE (Ø24.5 de 79.2→92.5),
  trous de bossage séparés Ø12.8 dans la paroi, tubes Ø26.5 ancrés 1.4 mm dans la paroi, avant-trous M3
  percés AVANT la coupe (trou continu au joint), coupe finale par booleen sur géométrie assainie.
- Artefacts résiduels : 12 arêtes à >2 faces (front) et 3 arêtes libres (back) à la face de joint, au droit
  des trous M3 — microscopiques, dans la matière du joint, sans effet impression (réparés par le slicer).

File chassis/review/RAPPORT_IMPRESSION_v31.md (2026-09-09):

# ₿ BalanceBot v3.1 — REVUE IMPRESSION 3D (audit mesuré)

> **SUITE APPLIQUÉE le 09/09/2026** (commits `eda934a` + `fe0570b`) — voir `NOTES_v3.md`, section
> « Révision du 09/09/2026 ». Résumé : alésages de palier débouchants (le tube gauche était bouché
> dans les STL committés → roue non montable), purge des voiles d'épaisseur nulle, bouchage du
> micro-trou 6,4 mm, plaques `export/v31` régénérées, `chassis/make_plates.py` ajouté.
> **Vérification finale : `chassis/review/verif_ultime.py` → 25/25** (0 arête libre, 0 non-manifold,
> watertight sur les 4 pièces, cotes et fonctions conformes).
> Les points de la section 5 (COUNTER 1,6 mm, interférence pneu, masse des roues) restent des choix
> de conception non tranchés — les réglages de slicing sont dans `NOTES_v3.md`.

Date : 09/09/2026 · Pièces auditées : `chassis/v3/*.stl` (état courant, 08/09 22:11-22:16)
Méthode : trimesh 5.1.0 + `dfam_tool.py` (45°) + `verify_stl.py` (bords libres, composantes, watertight) — mesures sur les STL, pas sur le générateur.

## 1. Fiche pièces (mesuré)

| Pièce | BBox (mm) | Volume | Masse 100 % PETG | Watertight | Composantes | Bords libres | Non-manifold |
|---|---|---|---|---|---|---|---|
| b_front | 132,1 × 23,0 × 201,0 | 109,0 cm³ | 138 g | non (ouvert au joint) | 4 | 164 | 39 |
| b_back | 132,1 × 34,9 × 201,0 | 94,9 cm³ | 121 g | non (ouvert au joint) | 3 | 157 | 102 |
| coin_wheel ×2 | 80 × 80 × 21 | 42,6 cm³ | 54 g | oui | 1 | 0 | 1927 |
| coin_tire ×2 | 83 × 83 × 7 | 4,4 cm³ | 5,6 g (TPU) | oui | 1 | 0 | 585 |

Total ≈ **378 g** (367 g PETG + 11 g TPU), temps estimé ≈ 10 h au profil actuel.

## 2. Ce qui est déjà bon

- **Orientation d'impression correcte** : face externe sur le plateau. Contact plateau : front 10 060 mm², back 17 093 mm², roue 4 244 mm² → adhérence large, aucun besoin de radeau.
- **Parois saines** : médiane 2,4 mm (= `WALL`), p05 1,6 mm (front), 2,4 mm (back). Aucune paroi sous 1,2 mm. Le `min_mm 0,129` du rapport DfAM est un échantillon parasite (piège connu).
- **Surplombs réels faibles** (faces descendantes HORS contact plateau) :
  - b_front : 5 831 mm² à 1,6 mm (creux COUNTER ₿), 593 mm² à 1,2 mm, 285 mm² à 13,5 mm → **~6,7 k mm²**
  - b_back : 702 mm² à 1,2 mm, 285 mm² à 13,5 mm → **~1,05 k mm²**
  - coin_wheel : 277 mm² à 0,8 mm + 314 mm² à 1,0 mm → **~590 mm²** (creux ₿ gravé)
  - coin_tire : **0**
- **Pneus** : 2,5 mm d'épaisseur constante, aucun surplomb, watertight.
- Roues/pneus des `export/v31/` sont **identiques** aux STL courants (4 474 / 1 024 triangles, mêmes volumes).

## 3. Anomalies de maillage (fiabilité slicer)

1. **Disque à épaisseur nulle dans l'alésage de palier GAUCHE** à x = −1,5 : Ø24,5, séparé en deux moitiés par le plan de joint (68 triangles dans le front + 68 dans le back), **non connecté à la coque**. Le moyeu Ø24×13 doit coulisser dans ce tube (12 mm) : ce voile réduit la profondeur utile à ~10,5 mm. Slicer = soit supprimé, soit imprimé sur 1 couche.
2. **Front** : 2 triangles isolés de 1,2 × 0,3 mm (slivers) à x = −1,5, z ≈ 30 → non-manifold.
3. **Back** : voile carré 3,4 × 3,4 mm au plan de joint (x ≈ 108, z ≈ 145), flottant (62 triangles).
4. **Micro-trou front** : boucle de 6,4 mm de périmètre (0,6 × 2,4 × 0,55 mm) à (45,5–46,1 ; 19,0–21,4 ; 138,6–139,1) → défaut booléen sous-millimétrique dans la paroi.
5. **Non-manifold** : 39 (front), 102 (back), 1 927 (roue), 585 (pneu). Les roues/pneus sont pourtant watertight (euler 0) : ce sont des sommets non soudés + triangles coplanaires du ₿ gravé → à nettoyer (`remove_doubles` + `dissolve_degenerate` + suppression des faces dupliquées + `recalc_face_normals`).

## 4. ⚠️ Incohérence de dépôt : les plaques `export/v31/` sont périmées

| Fichier | Triangles | Profondeur | Watertight | État |
|---|---|---|---|---|
| `chassis/v3/b_front.stl` (22:16) | 7 598 | 23,0 | non (OUVERT) | courant |
| `export/v31/plate1_b_front.stl` (14:44) | 8 298 | 23,0 | **oui (peau)** | **ancien** |
| `chassis/v3/b_back.stl` (22:11) | 8 207 | 34,9 | non (OUVERT) | courant |
| `export/v31/plate2_b_back.stl` (14:44) | 8 886 | **29,0** | non | **ancien** |

Le générateur a la peau sacrificielle **désactivée** (commentée, 08/09 soir) : version CREUSE validée par l'utilisateur. Les plaques du dossier `export/v31/` datent d'avant (version FERMÉE, peau 0,6 au joint, et profondeur de back différente). **Slicer ces plaques imprimerait l'ancien design.** À régénérer.

## 5. Optimisations proposées (par gain)

**A. Temps d'impression (−30 % ≈ −1 h 30 sur les 2 coques)**
- Hauteur de couche **0,28 mm** pour b_front/b_back (grandes surfaces plates, 2,4 mm de parois = 6 périmètres ; PETG OK jusqu'à 75 % du Ø buse). Garder 0,20 pour la roue (gravure ₿) et 0,24 pour le pneu.
- `brim` 5 mm + lit 70–80 °C + 1re couche 0,24 (pièce de 201 mm en PETG : gauchissement).

**B. Ponts / creux ₿ (le seul vrai surplomb)**
- 5 831 mm² de plafond plat à 1,6 mm (creux COUNTER du front) : soit garder et régler les ponts (débit 0,9 ; 25 mm/s ; ventilateur 100 %), soit **donner un dépouille 45° aux parois du creux** → le plafond plat disparaît, plus rien à ponter. Même correctif pour la roue (590 mm²).
- Les 285 mm² à 13,5 mm (identiques sur les 2 coques : lèvres de fenêtre / rails PCB) : chanfrein 45° sous la face ou vérification visuelle après première couche.

**C. Masse (optionnel — attention à l'inertie des roues)**
- Roues : 54 g pleines chacune. 4 périmètres + 20 % gyroid ≈ 30–32 g → −45 g au total, mais **l'inertie des roues participe à l'équilibrage** : à valider en simulation avant de trancher.
- Coques : ne pas descendre sous 2,4 mm de paroi (c'est la rigidité du châssis).

**D. Assemblage / tolérances**
- Pilote M3 autotaraudeuse : Ø2,6 → **Ø2,5** + chanfrein 0,5 mm en entrée (morsure PETG).
- Bande TPU : interférence 0,9 mm → **0,5–0,6 mm** (montage à la main sans étirer à outrance).
- Goujons Ø5,8 / alésages Ø6,0 : OK (0,2 de jeu).

**E. Nettoyage maillage** (avant export, dans le générateur)
- Supprimer le voile de palier gauche (le bore doit traverser jusqu'à x = −12,5), le voile carré du back et les slivers.
- `remove_doubles` + `dissolve_degenerate` + dédoublonnage des faces + `recalc_face_normals` avant export → non-manifold à 0.

**F. Documentation**
- `chassis/NOTES_v3.md` annonce encore « coques FERMÉES pour le slicer » alors que l'état validé est CREUX → à corriger (et la note équivalente du skill `balance-bot`).

## 6. Répartition des plaques (inchangée)
plate1 = b_front (201 × 132 au sol, h 23) · plate2 = b_back (h 34,9) · plateR = 2 roues · plateT = 2 pneus TPU.
Le CLI headless refuse les coques > 195 mm (dimension 201) → **slicer en GUI Bambu Studio** (déjà la pratique).

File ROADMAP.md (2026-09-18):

# Feuille de route — B-bot

Objectif : faire du B-bot un robot **qui tient, qui voit, qui réagit, et qui accueille** —
sans jamais perdre la loi du projet :

> **Le simulateur et le firmware doivent dire la même chose.**

Statuts : ✅ fait · 🔄 en cours · ⏳ à faire · 🔧 demande le robot ou l'imprimante sous la main.

---

## 1. Fondations

| # | Chantier | État | Détail |
|---|---|---|---|
| 1.1 | **CI « règle d'or »** | ✅ | `scripts/verifier-regle-or.py` compare les constantes du firmware (`config.h`, `head.cpp`) à celles des deux simulateurs, et `BALANCE_LOOP_HZ` à leur pas de temps. `.github/workflows/verifier.yml` le lance, plus l'auto-test du simulateur, la vérification que le bundle mono-fichier est à jour, l'absence de ressource externe, et la compilation du firmware. |
| 1.2 | **Deux cœurs** | 🔄 | La mesure ultrason bloque jusqu'à 9,5 ms pour un pas d'équilibre de 5 ms : la boucle saute un à deux pas à chaque mesure. Équilibre sur le cœur 0 (priorité haute), écran/tête/tuner sur le cœur 1, avec une compilation de repli mono-cœur. |
| 1.3 | **Arrêt sûr** | 🔄 | Roues coupées à la chute, surveillance de blocage de la boucle, et arrêt d'urgence matériel (bouton BOOT en appui long). |
| 1.4 | **Mode d'actionneur correct** | 🔄 | `FEET_MODE_CONTINUOUS` vaut 0 (servos 180°) alors que le robot a des **servos 360° continus** : c'est la divergence que le CI attrape désormais. |

## 2. Simulateur

| # | Chantier | État | Détail |
|---|---|---|---|
| 2.1 | **Capteurs HC-SR04** | ✅ | Modélisés en 3D **et** simulés, miroir de `head.cpp` (cadence adaptative 200 ms/1 s, lissage sur 5, portée 150 cm, alerte 25 cm, tête). Contre-vérifié par un agent indépendant. |
| 2.2 | **Corrections de la contre-vérification** | 🔄 | Le défaut bloquant : les animations faussaient la mesure du capteur (jusqu'à 1,34 cm). Plus : un seul module au lieu de deux (fidélité à la photo), aide du panneau, seuil réel 155/164 cm, trous de l'auto-test. |
| 2.3 | **Animations du corps** | ✅ | 5 animations cosmétiques, sans jamais toucher la physique. |
| 2.4 | **Guide utilisateur** | ✅ | `docs/GUIDE-SIMULATEUR.md`, avec 6 exemples d'effets et leurs effets **mesurés**. |
| 2.5 | **Presets d'effets** | ⏳ | Les 6 effets du guide en boutons, au lieu d'être recopiés en JavaScript. |
| 2.6 | **Comparaison A/B** | ⏳ | Deux jeux de gains côte à côte, même scénario, même graine. |
| 2.7 | **Recherche automatique des gains** | ⏳ | Le simulateur explore des centaines de jeux sur les 6 scénarios et sort les meilleurs — puis validation sur le robot. |
| 2.8 | **Rejeu d'un enregistrement réel** | ⏳ 🔧 | Enregistrer l'état du robot à 200 Hz pendant un essai, puis **rejouer ce log dans le simulateur** : la règle d'or devient mesurable. Le simulateur rejoue déjà le Python à la décimale ; il reste à ingérer un log du firmware. |
| 2.9 | **Bruit du capteur réel** | ⏳ 🔧 | Mesurer le bruit de l'IMU du robot et l'injecter dans le simulateur, pour que les verdicts « tient/chute » soient ceux du vrai robot. |
| 2.10 | **Batterie simulée** | ⏳ | Chute de tension sous charge et comportement « batterie faible ». |

## 3. Comportements du robot

| # | Chantier | État | Détail |
|---|---|---|---|
| 3.1 | **Évitement d'obstacle** | ✅ 🔧 | Firmware (`10044c0`) : ralenti < 60 cm, recul doux + pivot du côté libre < 25 cm, pivot seul après 1,5 s, hystérésis 35 cm, tête qui balaie ±30° en équilibre — par les consignes seulement, **jamais** en coupant l'équilibre. Miroir dans les deux simulateurs (couche déplacement + évitement, auto-test §6-8, bouton « Démo évitement »). Le simulateur prévient : sans boucle de vitesse, recul et avance sont des accélérations constantes → chute à la saturation des roues ; à confirmer sur le robot. |
| 3.2 | **« Suis-moi »** | ⏳ | Un correcteur simple sur la distance : garder ~50 cm. |
| 3.3 | **Pilotage au téléphone** | ⏳ | Une page de conduite tactile dans le point d'accès `BalanceBot-Tune` qui existe déjà. |
| 3.4 | **Animations portées sur le robot** | ⏳ 🔧 | Les 5 animations du simulateur, exécutées par les servos réels + le visage. |

## 4. Le robot d'accueil

| # | Chantier | État | Détail |
|---|---|---|---|
| 4.1 | **Voix** | ⏳ 🔧 | Micro I²S + ampli : le B-bot devient la tête d'un assistant local. Les briques existent déjà sur l'établi. |
| 4.2 | **Pourboires Lightning** | ⏳ | Le corps **est** un ₿ : facture LNbits affichée en QR sur l'écran, et un merci quand les sats tombent. Le LNbits et la boutique sont déjà en place. |
| 4.3 | **Comportement d'accueil** | ⏳ 🔧 | Il repère une approche (ultrason), se retourne, affiche un visage, propose quelque chose. C'est la somme de 3.1, 3.4 et 4.1. |
| 4.4 | **Tête articulée (châssis v3.2)** | ⏳ 🔧 | Le firmware pilote un pan/tilt que le châssis n'a pas : une tête porteuse (écran + capteurs) rendrait le balayage et les animations réellement visibles. C'est aussi la seule limite que le simulateur déclare. |

## 5. Matériel

| # | Chantier | État | Détail |
|---|---|---|---|
| 5.1 | **IMU moderne** | ⏳ 🔧 | Le MPU6050 est ancien (dérive, bruit). Un ICM-42688 ou BMI270 coûte quelques euros et améliore le signal à la source. |
| 5.2 | **Arrêt d'urgence** | 🔄 | Bouton matériel qui coupe le rail des servos. Un robot qui tient debout finira par tomber : 400 g de PETG sur une table, ça casse. |
| 5.3 | **Encodeurs de roue** | ✖️ | **Écarté volontairement** : autant apprendre la mesure de vitesse sur un autre robot, avec du matériel qui la mérite. |

## 6. Le projet

| # | Chantier | État | Détail |
|---|---|---|---|
| 6.1 | **Dépôt public + vitrine** | ✅ | `github.com/Silexperience210/balance-bot` : photo du prototype, aperçu animé, simulateur en ligne (GitHub Pages), 12 tags. |
| 6.2 | **Licence** | ⏳ | Le dépôt public n'en a aucune : sans licence, personne ne peut légalement réutiliser le travail. |
| 6.3 | **Traçabilité des essais** | ⏳ | Journal des flashs et des jeux de gains validés (une entrée par essai réel). |

---

## Ordre conseillé

1. **1.1 + 2.2** (terminer et publier ce qui est commencé) — la CI protège tout ce qui suit.
2. **1.2 + 1.3 + 1.4** (les deux cœurs, l'arrêt sûr, le mode correct) : c'est ce qui rend les essais réels fiables.
3. **3.1 + 3.3** (évitement + pilotage téléphone) : le robot devient vivant et manœuvrable.
4. **2.8 + 2.9** dès qu'un essai réel est enregistré : le simulateur devient *vrai*.
5. **4.2** (pourboires Lightning) : le plus fort rapport effet/effort de tout le volet « accueil ».
6. Le reste (4.1, 4.3, 4.4, 5.1, 5.2) demande le matériel et l'imprimante.

## Ce qui demande le robot ou l'imprimante

Tout ce qui est marqué 🔧 : l'essai de mise au point réel (le robot n'a jamais été flashé avec
les corrections de la revue croisée), le log de rejeu, le bruit mesuré de l'IMU, l'arrêt
d'urgence, la tête articulée, l'IMU moderne et le volet vocal.

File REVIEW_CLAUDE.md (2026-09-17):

# Confrontation — revue adversaire du firmware BalanceBot (Claude, 17/09/2026)

Cible : état du dépôt après le commit `2433f4e` (revue Kimi K3 + corrections Hermes).
Périmètre : `balance-bot/` (14 fichiers, lus intégralement) + `sim/balancebot_sim.py`.
Méthode : lecture ligne à ligne, **ré-exécution du simulateur** (version courante ET
version d'avant `2433f4e`, extraite par `git show`, exécutée depuis stdin — aucun fichier du
dépôt modifié), analyse linéaire du modèle (pôles), dérivation de Lagrange pour la physique,
lecture du `sdkconfig` du core ESP32 3.3.11 pour la question NVS.

Sévérités : **bloquant** / **important** / mineur / cosmétique.

Bilan chiffré : **6 désaccords** avec `REVIEW_KIMI.md` (dont 2 affirmations « vérifié sain »
fausses et 1 « conséquence mesurée » non reproductible), **17 trouvailles nouvelles**
(§4, M1-M19 hors M12/M13 qui prolongent des points de Kimi), dont **8 classées importantes**
— 4 sur la loi de commande / la sécurité du firmware (M1, M3, M6, M8), 2 sur la stratégie
de réglage (M10, M11), 2 sur le simulateur (M2, M4). Verdict en §6 ; **application des
corrections** (état par point, compilation, sim AVANT/APRÈS) en §7.

---

## 1. Les 5 corrections de `REVIEW_KIMI.md`

### #1 — `ui.cpp:511` `FaceFrame s_lastFrame` supprimée
- Verdict : **d'accord**. `grep -rn s_lastFrame balance-bot/` → aucune occurrence restante ;
  la variable n'était lue nulle part. Sans risque (agrégat trivialement constructible, pas
  d'effet de bord à la construction).

### #2 — `balance.cpp:61-63` commentaire « validées en simulation » réécrit
- Verdict : **d'accord sur le fond, désaccord sur l'exécution** (cosmétique). Le nouveau texte
  est désormais **dupliqué** : les lignes 45-49 disaient déjà exactement la même chose (« Gains
  de DÉPART, NON validés par une simulation rejouable (voir FIRMWARE_REVIEW.md §1bis) »). Le
  correctif a remplacé une phrase fausse par une paraphrase de 3 lignes d'un paragraphe situé
  12 lignes plus haut. Il fallait supprimer la ligne, pas la réécrire.
- Plus grave, le même bloc de commentaires contient une **procédure de réglage inapplicable**
  (lignes 40-43) que ni Kimi ni Hermes n'ont relevée — voir §4 M8.

### #3 — `feet.cpp:4,13` `FIT_NOTES.md §9` → `NOTES_v3.md`
- Verdict : **d'accord, mais correction incomplète** (cosmétique). `chassis/NOTES_v3.md`
  existe bien. Restent deux renvois au fichier purgé hors firmware :
  `TEST_PROTOCOL.md:12` (« palonnier calé (FIT_NOTES §9) » — c'est la check-list que
  l'utilisateur suivra au premier test) et `README.md:19` (« châssis v2 : … FIT_NOTES »).

### #4 — `feet.h:5` « v2 » → « v3.1 »
- Verdict : **d'accord, mais correction incomplète** (cosmétique). Le même « v2 » subsiste
  dans **`balance.cpp:15`** (« MÉCANIQUE v2 : plus de roues ») et **`interfaces.h:61`**
  (« servos de POSITION (mécanique v2 — plus de roues) »). Un `grep -n "v2\b"` suffisait.

### #5 — `sim/balancebot_sim.py:135` fenêtre `±0.02` → `DT/2` (« tape ×7 »)
- Verdict sur le code : **d'accord**. Vérifié : avec `DT = 5 ms`, `abs(k·DT − 3) < 0.02`
  est vrai pour k ∈ {597…603} = **7 pas** (calcul exact reproduit), donc `dtheta += push_v`
  était appliqué 7 fois. Ce n'était pas un « étalement volontaire » : un étalement
  volontaire s'écrirait `push_v · dt/0.04` (indépendant du pas) ; ici l'impulsion totale
  dépendait de `dt_sim`, paramètre que `run()` acceptait à l'origine (`b8aa15f`) — c'est la
  signature d'un bug, pas d'un choix. Le libellé « tape 0,4 rad/s » désigne bien une
  impulsion de vitesse unique. Physiquement, 7 × 1,2 = 8,4 rad/s aurait été un coup de
  0,67 m/s au CoM — hors de propos pour un robot dont la base parcourt ±25 mm.
- Fragilité mineure du correctif : `< DT/2` ne déclenche **rien** si `push_t` tombe à un
  demi-pas (ex. 3,0025 s : les deux voisins sont à exactement DT/2, `<` est faux). Un
  drapeau « appliqué une fois dès que `t ≥ push_t` » serait robuste. Sans effet sur les
  scénarios actuels (push_t = 3 est un multiple de DT ; `600·DT == 3.0` exactement).
- **Désaccord sur la « conséquence mesurée »** (important pour la crédibilité de la revue) :
  `REVIEW_KIMI.md` affirme « les scénarios « tape » passent de `chute θ` à `panic φ`
  (θfin +46° → +27°) ». **C'est faux, et non reproductible** : la version d'avant
  correctif (`git show 2433f4e^:sim/balancebot_sim.py | python3 -`) et la version
  courante produisent une sortie **strictement identique** (0/6, mêmes θfin/φfin au dixième).
  Cause : **les six scénarios échouent entre t = 0,35 s et t = 0,55 s**, or la tape est
  appliquée à t = 3 s. **Aucune tape n'a jamais été appliquée** dans le simulateur corrigé —
  ni avant ni après `2433f4e`. Les trois scénarios « tape » sont, dans les faits, trois
  répétitions de « θ0 = 3°, bruit » qui tombent à 0,41 s. Le correctif est juste mais
  **sans effet**, et la vérification annoncée n'a pas eu lieu (ou a été faite sur un autre
  état du dépôt). Preuve : temps d'échec par scénario, version courante :

  ```
  θ0=2° propre     panic φ  t_échec=0.41s
  θ0=2° bruit      panic φ  t_échec=0.41s
  θ0=5° bruit      chute θ  t_échec=0.35s
  tape 0.4 rad/s   panic φ  t_échec=0.41s   (push à t=3 → jamais atteint)
  tape 0.8 rad/s   panic φ  t_échec=0.41s
  tape 1.2 rad/s   panic φ  t_échec=0.41s
  ```

---

## 2. Les 5 suggestions non implémentées

### #6 — `feet.cpp:177` `driveFootSpeed(int, int)` : quantification entière
- Verdict : **d'accord que c'est négligeable — je descendrais à cosmétique**. 1 °/s de pas
  à 200 Hz = 0,005°/cycle, soit 0,055 µs d'impulsion : l'arrondi `lroundf(us)` de
  `footToUs()` (1 µs ≈ 0,09°) absorbe ~18 cycles avant que la consigne servo ne bouge. La
  quantification entière est un ordre de grandeur sous la résolution du servo. Seule
  incohérence réelle : `updateFootVel(out·k)` (`balance.cpp:587`) filtre la valeur
  **non** quantifiée alors que `feet.cpp` intègre la valeur quantifiée — écart < 0,5 °/s,
  sans conséquence. Passer en `float` reste propre, mais ce n'est pas un bug.

### #7 — `balance.cpp:237-247` throttling NVS qui **saute** l'écriture
- Verdict : **d'accord, et je remonte la raison** (mineur → important-si-on-règle-en-équilibre).
  Le constat de perte de la dernière valeur est exact (`now − s_lastSaveMs < 1500 → return`
  sans drapeau dirty ; la page web envoie un POST par relâcher de slider, deux relâchers en
  < 1,5 s perdent le second). Ce qui a été manqué : **l'écriture NVS se fait depuis la tâche
  web (cœur 0) et stalle le cœur 1**. Vérifié dans
  `~/.arduino15/packages/esp32/tools/esp32s3-libs/3.3.11/sdkconfig` :
  `CONFIG_SPI_FLASH_AUTO_SUSPEND is not set` → toute écriture/effacement flash désactive le
  cache et **suspend l'autre cœur** (celui de `Balance::loop()`). `Preferences::putFloat` →
  `nvs_set_blob` + `nvs_commit` (5 fois par sauvegarde) : ~1-3 ms de stall par POST, et
  10-40 ms (effacement de page, découpé par `CONFIG_SPI_FLASH_YIELD_DURING_ERASE=y` en
  tranches de 10 ms) tous les ~50 POST. Ce n'est pas catastrophique, mais c'est un argument
  supplémentaire — et décisif — pour la solution que Kimi proposait : **drapeau dirty +
  écriture au désarmement uniquement** (jamais pendant `g_state.balancing`).

### #8 — `Tuner::toggle()` cœur 1 / `serverTask` cœur 0
- Verdict : **d'accord (mineur)**. `s_up` est un `bool` non-`volatile` lu dans une boucle
  qui appelle des fonctions opaques (`handleClient`, `vTaskDelay`) : le compilateur le relit,
  la course est bénigne. À ajouter : `stopRadio()` coupe la radio pendant qu'un
  `handleClient()` peut être en cours sur l'autre cœur (socket fermé sous lui — lwIP le
  tolère) ; et surtout `.ino:133` fait un **`Serial.printf` depuis `loop()` (cœur 1)** sur
  l'appui long, alors que `STALL_ANALYSIS.md §6` a établi qu'une écriture USB-CDC bloque
  quand l'hôte ne draine pas le port. Appui long BOOT en plein équilibre = risque de
  gel de la boucle. Mineur (geste volontaire), mais incohérent avec la règle du projet.

### #9 — `sim:70` `tau_f = 0.025` vs commentaire « 0,25 s »
- Verdict : **d'accord sur la sévérité (important), désaccord sur le diagnostic**. Kimi
  présente une « divergence 10× à trancher ». Il n'y a rien à trancher : un filtre
  complémentaire n'a **aucun retard** sur le signal vrai (les voies gyro et accel se somment
  à 1 ; 0,25 s est la fréquence de croisement des capteurs, pas un lag). Modéliser 0,25 s de
  retard rendrait tout équilibre impossible. Les vrais retards de la chaîne sont : DLPF
  MPU6050 à 42/44 Hz (~5 ms), échantillonnage (2,5 ms moyen), et surtout la **trame PWM
  50 Hz du servo (0-20 ms, non modélisée)**. 25 ms est donc une valeur défendable comme
  retard *total* de boucle, mais rangé au mauvais endroit (appliqué au pitch ET au gyro comme
  « retard IMU »). Ce qui rend le point **important** : c'est ce paramètre non justifié qui
  fait basculer le verdict du sim sur les gains embarqués. Analyse linéaire du modèle du
  sim (servo 1er ordre 50 ms + filtre) pour Kp25/Ki500/Kd0,5 : pôle dominant **+1,32**
  (instable) avec 25 ms, **−0,15** (stable, marginal) sans. Le « 0/6 » des gains embarqués
  est, en partie, un artefact de ce 25 ms. Correction : mettre le commentaire en accord
  (« retard total de boucle ≈ DLPF + ZOH servo ») et documenter que le verdict en dépend.

### #10 — `interfaces.h` : `Tuner::toggle()` « non déclaré », commentaire `loop()` périmé
- Verdict : **désaccord sur la première moitié**. `Tuner::toggle()` **est déclaré** dans
  `tuner.h:20`, que le `.ino` inclut (`balance-bot.ino:13`) — sinon ça ne compilerait pas.
  Le constat exact est : « `toggle()`/`isUp()`/`lastRequestMs()` vivent dans l'en-tête
  privé `tuner.h` et non dans le contrat gelé `interfaces.h` ». Cosmétique.
  D'accord sur le commentaire `interfaces.h:86` (« sert au plus une requête ») périmé ;
  ajouter `interfaces.h:61` (« mécanique v2 », cf. #4).

---

## 3. Les affirmations « vérifié sain »

### « Cascade de recentrage : signe correct, cohérent sim↔firmware (BQ-BX) » — **FAUX**
- **`balance.cpp:305`** : `−kRecenterKv · (s_recenterVel − s_footVelFilt)`.
- **`sim/balancebot_sim.py:95-96`** : `+self.kv · (self.recenter_vel − self.foot_vel_filt)`.
- Mêmes conventions de part et d'autre (setpoint dans les unités du pitch, `err = ref −
  pitch`, vitesse de pied = −PID, `foot_vel_filt` = vitesse de pied filtrée, `recenter_vel`
  = Kpφ·(0−φ) rampé) : les deux boucles internes sont de **signes opposés**. Historique
  (`git show 6aabd3c`) : la faute n°12 du 09/09 a inversé le signe dans le firmware, et le
  même commit a écrit la cascade du sim… avec l'ancien signe. `FIRMWARE_REVIEW.md` (faute 13
  « cascade portée à l'identique ») et `REVIEW_KIMI.md` (« cohérent ») sont donc faux tous
  les deux sur ce point, et la **RÈGLE D'OR du projet est violée** depuis 8 jours.
- Quel signe est juste ? Non tranché, et la preuve invoquée par la faute 12 est caduque :
  · l'argument physique standard d'une cascade vitesse sur pendule inversé est **(+)** : pour
    accélérer la base vers l'arrière il faut pencher vers l'arrière ;
  · l'argument de la faute 12 (« pied lâché à +20° → +37° en 0,3 s ») décrit le régime
    **transitoire** (à non-minimum de phase : pour créer un penché arrière, le PID commence
    par envoyer le pied en avant) — et il ne domine que parce que Kv·RefMax sature
    (Kv = 3, ±6° → P = 25×6 = 150 → sortie à ±90 °/s dès 2 °/s d'erreur de vitesse) ;
  · dans le sim corrigé, **les deux signes donnent 0/6** et échouent en < 0,5 s (voir M4) :
    la simulation qui a décidé du signe ne tient pas le PID seul, elle ne pouvait rien
    prouver sur la cascade.
- Recommandation : premiers essais réels avec **`kv = 0` via le banc web** (la contribution
  θ_ref devient nulle, la garde `kFootPanicDeg` reste active) ; re-décider le signe et
  Kv ≪ 1 avec un sim qui tient d'abord le PID seul.

### « Physique du sim : θ̈ = (g/h·sinθ − R/h·φ̈·cosθ)/(1 + R/h·cosθ) exacte (BY) » — **FAUX**
- C'est l'approximation « chariot-pendule » (pivot d'accélération imposée a = R(θ̈+φ̈)),
  qui **oublie le couple de réaction du servo sur le corps** (le servo est vissé sur le
  corps : le couple qu'il applique à l'arc s'applique en retour au corps — exactement le
  terme moteur des équations du Segway) et le terme centrifuge. Lagrangien pour une masse
  ponctuelle m à h au-dessus de l'axe, arc de rayon R centré sur l'axe roulant sans glisser
  (x = R(θ+φ), V = mg(R + h cosθ)) :

  ```
  θ̈ · (R² + 2Rh cosθ + h²) = g h sinθ − φ̈ · R (R + h cosθ) + R h sinθ · θ̇²
  ```

  Aux petits angles : autorité de commande **identique** (−φ̈·R/(R+h) dans les deux
  modèles), mais terme de gravité **g·h/(R+h)² = 62,0 s⁻²** (exact) contre
  **g/(R+h) = 87,2 s⁻²** (sim) : pôle instable 7,87 rad/s contre 9,34 rad/s. Le sim est
  **~19 % plus pessimiste** que sa propre hypothèse « masse ponctuelle ». Vérifié
  numériquement : ça ne change pas le 0/6 des gains embarqués (mineur, conservateur), mais
  le mot « exacte » (docstring l. 6, `FIRMWARE_REVIEW.md` faute 13, `REVIEW_KIMI.md` BY)
  doit disparaître.

### « `demoStep` non appelé quand `s_rateLow`/`s_imuLost` (AK) » — vrai, mais…
- Vrai (`balance.cpp:414-418`, `475-480` retournent avant). Ce qui a été manqué : la
  branche **`!s_imuOk`** (`balance.cpp:447-448`) appelle `halt()` **puis** `demoStep()`, et
  `halt()` → `Feet::stop()` → **`s_lastMicros = micros()`** (`feet.cpp:210`) ; le
  `driveFootSpeed()` qui suit quelques µs plus tard voit `dt ≈ 20 µs` → borné à
  `kDtMinS = 0,5 ms` (`feet.cpp:183`) au lieu des 5 ms réels → **la démo sans IMU roule 10×
  trop lentement** (2 °/s au lieu de 20 °/s). C'est précisément le « mode démo UI
  seulement » annoncé par le `.ino` pour valider la mécanique. Mineur, mais c'est un bug
  fonctionnel, pas une nuance. Fix : ne pas appeler `halt()` à chaque itération dans cette
  branche (un `halt()` sur front suffit), ou ne pas réarmer `s_lastMicros` dans `stop()`.

### « `isFallen` vs `obstacle` distincts (AL) » — vrai. Rien à redire.

### « IMU muet → retour `false` géré (AW) » — vrai pour un NACK, **faux négatif** pour un
capteur figé
- `imu.cpp:185` ne détecte que l'échec de transaction. Un MPU6050 qui **ACK mais renvoie
  des données figées** (capteur en reset/veille après un creux d'alimentation, trame de
  zéros : `norm = 0` → `trustAccel = false` → gyro seul avec `rate = −biais/65,5`) fait
  asservir le robot sur un angle mort **sans jamais déclencher `s_imuLost`**. Test de
  vivacité à coût nul : N trames brutes consécutives strictement identiques (les 7 int16)
  ⇒ traiter comme trame perdue. Mineur/important selon la qualité du câblage volant.

### « Anti-windup identique sim/firmware (BS) » — vrai, mais il ne protège pas de ce qui
fait tomber le robot (cliquet de la mort-zone, M3) ni du plafond `kIntegralMax` (M10).

### « Butée unique `FOOT_HARD_DEG` » — vrai (`config.h:70`, `feet.cpp:66`, `balance.cpp:109`).

### « Le 0/6 vient du fait que le pied consomme ses ±45° puis panique » — description
correcte du symptôme, **diagnostic incomplet** : voir M3/M4/M10/M11 — ce n'est pas « les
gains », c'est la structure (mort-zone, plafond intégral, autorité 90 °/s, saturation de
la cascade).

---

## 4. CE QUI A ÉTÉ MANQUÉ (trouvailles nouvelles, par sévérité)

### M1 — Signes opposés de la boucle interne de la cascade (sim ≠ firmware) — **important**
Détaillé en §3. `balance.cpp:305` (−Kv) vs `sim:95-96` (+Kv). Violation de la règle d'or,
signe non tranché, preuve du 09/09 caduque. Action : `kv = 0` au banc pour les premiers
essais ; aligner le sim sur le firmware (ou l'inverse) **explicitement**, avec un
commentaire croisé des deux côtés.

### M2 — Le soft clamp du simulateur est orienté à l'envers — **important (sim / règle d'or)**
`sim:110` : `if out * self.phi_cmd > 0:` où `out` est la sortie PID **non inversée** ; la
vitesse de pied réelle est `u = −out` (`sim:127`). Le pied s'éloigne de la butée quand
`u·φ > 0` ⇔ `out·φ < 0`. Le sim atténue donc… **le retour vers le centre**, et laisse la
poussée vers la butée à pleine autorité. Le firmware est juste (`balance.cpp:579-582` :
inversion **avant** `limitTowardStop`, `out·footAvg ≤ 0 → libre`). L'auteur du sim avait vu
le piège pour l'estimateur (commentaire l. 114-115, `cmd_vel = −out`) mais pas pour le clamp.
`FIRMWARE_REVIEW.md §2` (« même formule que la sim ») compare la formule, pas le signe de la
condition. Effet sur le 0/6 : nul (le clamp n'agit que dans les 10° avant la butée, zone où
la panique à 35° arrive avant) — mais c'est exactement le genre d'écart que la règle d'or
interdit, et il fausserait toute étude du comportement près des butées. Fix : tester
`(−out) * phi_cmd > 0`.

### M3 — Mort-zone d'erreur 0,25° + intégrateur = cliquet → chute garantie en ~1,5 s — **important (firmware)**
`balance.cpp:86` (`kErrDeadbandDeg = 0.25f`) appliquée l. 565 **avant** P et I ; même
chose `sim:47,100`. Mécanisme (trace reproduite ci-dessous, Kp = 100 / Ki = 500 / Kd = 0,5,
θ0 = 0,25°, cascade OFF, clamp orienté comme le firmware) : le robot vit sur le **bord** de
la mort-zone ; chaque sortie au-dessus de +0,25° donne un coup de P qui le ramène juste
dedans, où P et I sont gelés ; l'erreur n'est donc **jamais de l'autre signe**, l'intégrale
n'a rien pour se décharger et **cliquette jusqu'à sa borne** (−25 = 25 °/s de dérive
permanente des pieds) → butée en ~1,3 s → chute. Ce jeu est **linéairement stable** (pôle
dominant −2,87 avec les deux retards) : la chute est due à la seule mort-zone.

```
   t     θ°    φcmd°    I     out        deadband=0.25 → chute@1.36 s (I∈[−25,0], monotone)
 0.10  +0.21   +1.5   −6.6  −31.1       deadband=0    → OK 6 s, φfin +2,4° (I∈[−8.6,0])
 0.30  +0.28   +4.5  −13.8  −43.9
 0.50  +0.33  +10.4  −24.8  −58.1       Idem Kp50/Ki350/Kd1 : chute@1.18 s → OK
 0.70  +0.41  +19.5  −25.0  −65.1       Idem avec bruit IMU + physique exacte : chute@1.79 s → OK
 1.00  +1.01  +39.8  −25.0  −90.0
 1.20  +9.34  +44.2  −25.0  −90.0
```

Sur le robot réel, le bruit IMU et la mort-zone propre du SG90 (~1° ≈ 0,57 mm) brouilleront
le cycle limite, mais le mécanisme (I n'intègre que hors bande et ne se décharge jamais dans
la bande) est structurel. Conséquence pratique : **une campagne de réglage avec cette
mort-zone verra les pieds partir en butée en 1-2 s quels que soient les gains**, et on
accusera les gains. Fix (3 caractères) : `kErrDeadbandDeg = 0.0f` — la justification
« tremblement dû au bruit IMU » ne tient pas (bruit du pitch fusionné ~0,03-0,1° rms, et
le servo ne répond pas sous ~1° de toute façon) ; si une bande est voulue, l'appliquer au
seul terme P, jamais à l'entrée de l'intégrateur. Porter au sim (`DEADBAND = 0`).

### M4 — Le « 0/6, aucun jeu de gains ne tient » est un artefact de structure, pas un fait sur les gains — **important (projet)**
Faits établis par ré-exécution :
1. **Tous** les scénarios échouent en 0,35-0,55 s, **avant la tape** (cf. §1 #5) : les trois
   scénarios « tape » n'ont jamais été joués.
2. **118 des 560** combinaisons (Kp, Ki, Kd, k_out ∈ {1, 3}) du balayage sont
   **linéairement stables** dans le propre modèle du sim (servo 50 ms + filtre 25 ms), et
   pourtant le sim non-linéaire n'en fait tenir **aucune**, même à θ0 = 0,25°. Un modèle
   linéairement stable qui tombe à 0,25° n'est pas « mal réglé » : une non-linéarité le tue.
3. Les non-linéarités en cause, isolées une à une : (a) la mort-zone (M3) — à elle seule
   suffisante ; (b) `kIntegralMax = 25` (M10) ; (c) `kOutToFootDegS = 1` → 90 °/s ≈ 51 mm/s
   de base, non balayé (M11) ; (d) le retard de 25 ms (§2 #9). Avec (a) = 0, (d) = 5 ms,
   Imax = 90 et k_out = 3, les gains embarqués tiennent les scénarios θ0 = 2° (φfin ±10°)
   et deux des trois tapes sont enfin **atteintes** (échec juste après, à 3,2-3,4 s ; la
   troisième tombe à 2,8 s sur son seul θ0 = 3° bruité) : dans ce modèle, 0,4-1,2 rad/s
   sont trop violentes pour ±25 mm de course — limite du robot, pas des gains.
4. La cascade, avec l'un ou l'autre signe et dans **toutes** les configurations testées,
   **aggrave** le résultat (panique à 0,2-0,4 s) : Kv = 3 avec ±6° de θ_ref × Kp ≥ 25 sature
   la sortie au premier écart de vitesse. En l'état c'est un passif, pas une aide.

Conclusion à substituer à « gains à re-régler en réel » : *le simulateur, tel qu'il est,
ne peut valider aucun jeu de gains, et ses échecs sont dominés par quatre choix structurels
(dont deux sont dans le firmware : mort-zone, plafond intégral) et par l'autorité 90 °/s.*
Chercher des gains avec lui avant de corriger ces points est du temps perdu.

### M5 — Physique du sim non « exacte » (couple de réaction servo) — mineur (conservateur)
Détaillé en §3. Retirer « exacte » ; optionnel : adopter l'équation de Lagrange ci-dessus
(3 lignes) — le sim devient ~19 % moins pessimiste sur la gravité, sans changer l'autorité.

### M6 — « Refus d'armer sur batterie faible » désarme aussi **en plein équilibre**, sur un seul échantillon ADC — **important (sécurité)**
`balance.cpp:424-427` s'exécute à **chaque** itération (pas seulement sur le front montant) :
dès que `g_state.batteryLow` passe à vrai, `cmdEnabled` est effacé → front descendant →
`halt()` → le robot debout **tombe**. Or `batteryLow` vient d'**une seule** conversion
`analogReadMilliVolts` par seconde (`battery.cpp:36`, `.ino:140-144`), sans moyenne ni
hystérésis, comparée à 3,5 V. Une LiPo 1S à mi-charge (~3,7 V à vide) sous un appel de 4
SG90 (pointes de 1-2 A, résistance interne + câblage volant) plonge transitoirement sous
3,5 V : **un échantillon malchanceux suffit à faire tomber un robot qui tenait**. L'intention
documentée (A4 : « la demande d'armement est annulée ») est une garde d'**armement** ;
l'implémentation est une coupure permanente. Fix : n'annuler que sur le front montant
(`want && !s_enabled`), et exiger N lectures consécutives basses (ou hystérésis 3,5/3,6 V)
pour déclarer `batteryLow`. Sur USB seul (`batteryV = −1`) le problème est inerte, ce qui
explique qu'il n'ait pas été vu au banc.

### M7 — Démo sans IMU 10× trop lente — mineur
Détaillé en §3 (AK). `balance.cpp:447-448` + `feet.cpp:210,183`.

### M8 — Procédure de réglage (`balance.cpp:40-43`) inapplicable et contradictoire — **important (pilote la campagne de réglage)**
« robot tenu à la main, **Ki = Kd = 0**, monter Kp jusqu'à oscillation ; puis Kd pour
amortir ; puis Ki pour la dérive lente ». C'est la recette d'un PID en **position**. Ici la
sortie est une **vitesse** de pied, donc l'accélération de la base (la seule chose qui
redresse le pendule) est la *dérivée* de la sortie : Ki·θ + Kp·θ̇ + Kd·θ̈. Autrement dit
**Ki est la raideur, Kp l'amortissement, Kd une inertie** — et le commentaire lui-même le
dit dix lignes plus bas (l. 51-56 : « Il faut Ki > g/R ≈ 301… en dessous, le robot tombe
quelle que soit la valeur de Kp »). L'étape 1 (Ki = 0) ne peut **jamais** produire une
oscillation observable, et l'étape 2 (« monter Kd pour amortir ») fait l'inverse de ce
qu'elle annonce. Analyse linéaire du modèle du sim (retards 50 + 25 ms) : Kp = 25 → instable
(+1,32) ; Kp = 50-100 → amortissement franc (pôle dominant −2,3 à −2,9). Réécrire : (1) Ki ≈ 400-500 d'emblée
(> 302), Kp ≈ 50, Kd ≈ 0,5 ; (2) monter **Kp** pour amortir ; (3) Kd en dernier, petit.

### M9 — IMU figée mais ACK non détectée — mineur/important
Détaillé en §3 (AW). `imu.cpp:181-203`.

### M10 — `kIntegralMax = 25` (28 % de `kOutMax`) plafonne le seul terme qui redresse — important (réglage)
`balance.cpp:81`. Dans cette architecture, I est le terme de raideur (cf. M8) ; le borner
à 25 °/s de sortie, c'est plafonner l'accélération cumulée de la base à une fraction de
l'autorité. Mesuré (deadband 0, τ_f 5 ms, k_out 3, cascade OFF, gains embarqués) : Imax = 25
→ 0/6 (chute à 1,8 s) ; Imax = 90 → 2/6 (θ0 = 2° tenus, φfin ±10°). Le commentaire justifie
la borne par le rebond au redressement — l'intégration conditionnelle (l. 194-199) s'en
charge déjà. Fix : `kIntegralMax = kOutMax`.

### M11 — `kOutToFootDegS = 1.0` : 90 °/s, < 25 % d'un SG90, `constexpr`, jamais balayé — important (stratégie de réglage)
`balance.cpp:99`. Le commentaire (l. 97-98) le désigne comme « le PREMIER bouton à monter »
— mais il n'est ni au banc web ni dans le balayage du sim (`--sweep` ne varie que Kp/Ki/Kd,
avec `OUT_TO_FOOT_DEGS = 1`). Le sim ne fait tenir un scénario θ0 = 2° **que** pour
k_out = 3. 51 mm/s de base pour rattraper 2° de penché, c'est peu : un pendule de 8 cm a
une constante de temps de ~0,1 s. Fix : exposer `kOutToFootDegS` au banc (borné 1-3,
persisté), ou le fixer à 2-3 avant la campagne ; l'ajouter au `--sweep`.

### M12 — NVS depuis le cœur 0 stalle le cœur 1 — mineur (vérifié sdkconfig)
Détaillé en §2 #7. Renforce « écrire au désarmement ».

### M13 — Restes de la revue précédente — cosmétique
`balance.cpp:15` et `interfaces.h:61` (« v2 ») ; `interfaces.h:86` (commentaire `loop()`) ;
`TEST_PROTOCOL.md:12`, `README.md:19` (`FIT_NOTES`) ; `balance.cpp:61-63` (paraphrase des
l. 45-49). Un `grep` aurait tout attrapé d'un coup.

### M14 — `Serial.printf` dans `loop()` cœur 1 (`.ino:133`) — mineur
Détaillé en §2 #8. Contraire à la règle établie par `STALL_ANALYSIS.md §6`.

### M15 — Page web : slider Kd borné à 10 (`tuner.cpp:125`) alors que `kKdMax = 20` ; `send()` (l. 142) reposte les 5 sliders — cosmétique/mineur
Un Kd > 10 posé par `curl` est affiché tronqué à 10 par le navigateur puis **réécrit à 10**
au premier geste sur n'importe quel autre slider. Aligner `max="20"`.

### M16 — Réarmement sans recentrage : panique probable si les pieds ont été laissés > ~25° — mineur (documenté, à connaître)
Après un STOP les pieds restent où ils sont (voulu, `halt()`). Au réarmement, aucun
`recenterNow()` (seul le chemin « chute + 700 ms droit » le fait) : avec `footAvg` ≈ 30°,
le premier transitoire franchit `kFootPanicDeg = 35°` → `s_fallen = true` → « CHUTE »
robot debout. Contournement existant : ramener les pieds aux flèches en MANUEL (la démo
autorise le retour vers 0 au-delà de ±15°). À documenter dans `TEST_PROTOCOL.md`, ou
recentrer sur front montant quand |pitch| < 10° et |rate| faible (robot tenu).

### M17 — Ce que le sim ne modélise toujours pas, et qui dominera le réel — mineur (documentation)
Trame PWM 50 Hz (0-20 ms de latence, échantillonneur-bloqueur), **mort-zone du SG90
(~5-10 µs ≈ 0,5-1° ≈ 0,3-0,6 mm de base)**, pas de borne d'accélération (φ̈ impulsionnel
au premier pas : +800 °/s² dans les traces). La mort-zone servo produira un cycle limite
de quelques degrés que le sim ne peut pas prédire. À ajouter à la docstring (l. 26-27).

### M18 — `Imu::calibrate()` : retour ignoré, 400 « échantillons » = 60 vrais — mineur
`balance.cpp:384` ignore le `false` (bus instable → biais gyro à 0, non signalé).
`imu.cpp:171` lit à ~1,4 kHz un capteur configuré à 200 Hz (`kSmplrtDiv = 4`) : 400
lectures ≈ 60 échantillons distincts lus 7× chacun — moyenne correcte mais bruit du biais
√7 fois plus grand qu'annoncé. Lire à 200 Hz pendant 2 s (400 vrais points), et logguer
l'échec.

### M19 — Reprise automatique après `s_imuLost` / `s_rateLow` — à discuter (mineur)
`balance.cpp:414-418`, `472-480` : l'asservissement reprend seul dès que le capteur/la
cadence revient, sur une estimation d'angle qui n'a pas intégré le gyro pendant la coupure
(reconvergence ~0,25 s par l'accel) et un état du robot inconnu. Documenté comme voulu
(« reprise automatique ») ; sur un robot tenu à la main c'est acceptable, sur un robot
libre ce n'est pas plus sûr que d'exiger un réarmement. Je le signale sans le contester.

---

## 5. Désaccords (synthèse)

| # | Ce que `REVIEW_KIMI.md` / Hermes affirme | Mon verdict | Preuve |
|---|---|---|---|
| D1 | #5 « conséquence mesurée : tape passe de chute θ à panic φ, θfin +46° → +27° » | **Faux, non reproductible** : sortie identique avant/après ; aucun scénario n'atteint t = 3 s | §1 #5 (ré-exécution des deux versions) |
| D2 | « Cascade : signe correct, cohérent sim↔firmware » | **Faux** : `−Kv` (`balance.cpp:305`) vs `+Kv` (`sim:96`) depuis `6aabd3c` | §3, M1 |
| D3 | « Physique θ̈ exacte » | **Faux** : approximation chariot-pendule, couple de réaction servo omis (pôle 9,34 vs 7,87 rad/s) | §3, M5 |
| D4 | #10 « `Tuner::toggle()` non déclaré » | **Faux** : déclaré `tuner.h:20`, inclus par le `.ino` | §2 #10 |
| D5 | #9 « divergence 10× à trancher » (0,25 s vs 0,025) | Rien à trancher : 0,25 s serait physiquement absurde ; le vrai enjeu est que le verdict du sim dépend de ce 25 ms non justifié | §2 #9 |
| D6 | « Le 0/6 ⇒ gains à re-régler » (conclusion reprise de `FIRMWARE_REVIEW §1bis`) | Diagnostic incomplet : mort-zone (cliquet), `kIntegralMax`, autorité 90 °/s, saturation cascade ; des jeux linéairement stables tombent à 0,25° | M3, M4, M10, M11 |
| — | #3/#4 corrections « appliquées » | Incomplètes (`balance.cpp:15`, `interfaces.h:61`, `TEST_PROTOCOL.md:12`, `README.md:19`) | §1 #3-#4 |
| — | « Soft clamp : même formule que la sim » (`FIRMWARE_REVIEW §2`, repris par le silence de Kimi) | Même formule, **condition inversée** dans le sim | M2 |

Points où je suis **d'accord** avec la revue initiale : #1, le fond de #2, le code de #5,
#6 (voire moins grave), #7 (voire plus grave), #8, AL, la butée unique, l'anti-windup
identique, le compte « 0/6 » lui-même (reproduit à l'identique, y compris pour mes
variantes de physique).

---

## 6. Verdict final

**À corriger avant le prochain flash** — si, comme tout le dépôt l'indique, ce flash est
celui de la campagne de réglage réel. Aucune des trouvailles ne rend le firmware dangereux à
flasher pour vérifier la mécanique, le signe de l'IMU et le neutre des pieds (les gardes
chute / IMU muette / cadence / servos non attachés / panique sont saines) ; mais deux
défauts feront échouer ou mal interpréter la campagne de réglage, et coûtent quelques lignes :

1. **`balance.cpp:86` `kErrDeadbandDeg = 0.0f`** (M3) — sinon les pieds partent en butée en
   1-2 s quels que soient les gains, et on accusera les gains. Porter `DEADBAND = 0` au sim.
2. **`balance.cpp:424-427`** : garde batterie sur le **front montant seulement** + hystérésis
   / N échantillons (M6) — sinon un creux de tension d'un seul échantillon fait tomber un
   robot qui tenait (inerte sur USB, actif sur batterie).
3. **`kv = 0` au banc web** avant toute autre chose (M1) — aucune modification de code ; la
   cascade telle que réglée est un passif avec l'un ou l'autre signe, et son signe est
   non tranché.
4. Fortement recommandé dans le même flash : `kIntegralMax = kOutMax` (M10) et
   `kOutToFootDegS` exposé au banc ou monté à 2-3 (M11) ; réécrire la procédure de réglage
   (M8) ; `halt()` sur front seulement dans la branche sans IMU (M7).

Et **avant toute nouvelle recherche de gains avec le simulateur** (sinon ses verdicts sont
sans valeur) : condition du soft clamp (M2), signe de la cascade aligné (M1), `DEADBAND`,
justification du retard de 25 ms (§2 #9), retrait du mot « exacte » et, idéalement,
équation de Lagrange (M5), `OUT_TO_FOOT_DEGS` dans le balayage (M11), et vérifier qu'un
scénario **atteint** sa tape avant de conclure quoi que ce soit sur les tapes.

Sur la méthode de la revue précédente : la « vérification ligne par ligne » a validé une
conséquence mesurée qui ne se produit pas (D1) et deux « vérifié sain » démontrablement faux
(D2, D3). Le simulateur est le seul instrument de validation du projet : la règle d'or
(mêmes boucles que `balance.cpp`) est aujourd'hui violée sur deux signes, et personne ne
l'a fait tourner assez loin pour voir qu'aucune tape n'était jamais appliquée.

---

## 7. Application des corrections (17/09/2026 — arbre de travail, commit à venir)

Périmètre appliqué : `balance-bot/` (balance.cpp, imu.cpp/h, battery.cpp/h, tuner.cpp,
ui.cpp — commentaires seuls —, interfaces.h, .ino), `sim/balancebot_sim.py`,
`TEST_PROTOCOL.md`, `README.md`. Rien n'a été flashé ni commité ; gains kKp/kKi/kKd
(25/500/0,5) et structure de la loi de commande inchangés.

| # | Correction | État | Où / comment |
|---|---|---|---|
| M1 | Signe de la boucle interne de la cascade sim ≠ firmware | **appliquée (commit à venir)** | Sim aligné sur le firmware : `-self.kv · (v_cible − φ̇)` (`sim:139`). Commentaire croisé des deux côtés (`balance.cpp` `recenterSetpoint()`, `sim` boucle interne) : « signe NON tranché — à décider en réel, commencer Kv = 0 au banc web ». Le signe n'a pas été tranché ; l'ancien commentaire « vérifié en simulation » est remplacé par le constat de caducité. |
| M2 | Soft clamp du sim orienté à l'envers | **appliquée** | `if (-out) * self.phi_cmd > 0:` (`sim:163`), avec le raisonnement du signe en commentaire. |
| M3 | Mort-zone d'erreur 0,25° + intégrateur = cliquet | **appliquée** | `kErrDeadbandDeg = 0.0f` (`balance.cpp`) et `DEADBAND = 0.0` (sim). Justification réécrite (bande sur P seul si jamais nécessaire). Vérifié dans le sim corrigé : Kp100/Ki500/Kd0,5, θ0 = 0,25°, cascade OFF → bande 0,25° : chute à 1,75 s avec I en butée ; bande 0 : tenu 6 s, φfin +1,6°. Idem Kp50/Ki350/Kd1 (1,52 s → OK) et Kp50/Ki500/Kd0,5 (1,59 s → OK). |
| M5 | Physique « exacte » (couple de réaction servo omis) | **appliquée** | Équation de Lagrange dans `run()` : `θ̈·(R² + 2Rh·cosθ + h²) = g·h·sinθ − φ̈·R·(R + h·cosθ) + R·h·sinθ·θ̇²`. Docstring réécrite (dérivation, petits angles 62,0 s⁻² vs 87,2, pôle 7,87 vs 9,34 rad/s) ; le mot « EXACT » a disparu. |
| M6 | Garde batterie = coupure en plein équilibre sur 1 échantillon | **appliquée** | `balance.cpp` : garde sur le **front montant** seulement (`want && !s_enabled && g_state.batteryLow`) — l'armement reste refusé, un robot debout n'est plus coupé. `battery.cpp` : `batteryLow` exige **3 lectures valides consécutives** < 3,5 V et retombe seulement au-dessus de **3,6 V** (hystérésis, `BAT_LOW_CLEAR_V = BAT_LOW_V + 0,1`, constantes locales — `config.h` non touché). Commentaires `interfaces.h`, `battery.h`, `ui.cpp` mis en accord (l'UI affiche toujours « BAT. FAIBLE », désormais aussi comme invitation à poser un robot debout). |
| M7 | Démo sans IMU 10× trop lente | **appliquée** | `halt()` sur front seulement dans la branche `!s_imuOk` (drapeau statique `s_noImuHalted` ; `s_imuOk` est figé au boot, le front est la première itération). `Feet::stop()` inchangé. |
| M8 | Procédure de réglage inapplicable (recette d'un PID de position) | **appliquée** | Commentaire `balance.cpp:40-53` réécrit pour une sortie en VITESSE : Ki = raideur (≈ 400-500 d'emblée, > g/R ≈ 302), Kp ≈ 50 = amortissement (monter Kp pour amortir), Kd = inertie, petit et en dernier. Le 301 → 302 de la condition de stabilité (9,81/0,0325 = 301,8) harmonisé. |
| M9 | IMU figée mais ACK non détectée | **appliquée** | `imu.cpp` : `readLive()` compare la trame brute (7 int16) à la précédente ; au-delà de `kFrozenMax = 4` trames strictement identiques consécutives, `update()` renvoie `false` → alimente `s_imuFailStreak`/`kImuFailMax` de `balance.cpp` (coupure à 24 trames ≈ 120 ms). Seuil > 1 parce que la cadence millis() du .ino peut relire le même échantillon (lecture < 5 ms après la précédente). Réinitialisé dans `begin()`. |
| M10 | `kIntegralMax = 25` plafonne le terme de raideur | **appliquée** | `kIntegralMax = kOutMax` (bloc anti-windup déplacé après `kOutMax`), `INTEGRAL_MAX = OUT_MAX` dans le sim. Le rebond au redressement reste géré par l'intégration conditionnelle. Effet mesuré (gains embarqués, k_out 3, Kv 0) : panic à 1,13 s (Imax 25) → 1,65 s (Imax 90). |
| M11 | `kOutToFootDegS` constexpr, jamais balayé | **appliquée** | Firmware : `float kOutToFootDegS` borné `kOutToFootMin..Max` = 1..3, API `Balance::setOutScale()/getOutScale()` (ajout non intrusif dans `interfaces.h`), clé NVS « kout » (écriture dans `saveGains()`, relecture bornée dans `begin()`), slider « Autorité kOut » 1-3 pas 0,1 sur la page web + champ `kout` dans `/api/state` et `/api/gains` (tampon 512 o : +11 o, marge conservée). Sim : paramètre `k_out` de `Sim` appliqué à la commande physique (`u = −ctrl()·k_out`) ET à l'estimateur φ̇ ; `--sweep` balaie k_out ∈ {1, 2, 3} ; 4ᵉ argument positionnel `k_out` en CLI. |
| M13 | Restes cosmétiques | **appliquée** | « v2 » → « v3.1 » (`balance.cpp:15`, `interfaces.h:61`) ; commentaire `Tuner::loop()` (`interfaces.h:86`) ; `FIT_NOTES §9` → `chassis/NOTES_v3.md, § Montage` (`TEST_PROTOCOL.md:12`) ; `README.md:19` → « châssis v3.1 : gen_bitcoin_bot.py + STL (v3/) + NOTES_v3.md » (gen_chassis.py n'existe pas non plus) ; paraphrase `balance.cpp:61-63` supprimée, §45-49 conservé. |
| M14 | `Serial.printf` dans `loop()` cœur 1 sur appui long | **appliquée (élargie)** | `.ino:133` : plus aucun `Serial` — `(void)Tuner::toggle()`. Comme `startRadio()`/`stopRadio()` écrivaient aussi sur Serial depuis ce même chemin, leurs traces sont regroupées dans `announce()`, appelée depuis `begin()` (setup) et, sur `toggle()`, par la tâche serveur (cœur 0) via un drapeau `volatile s_announce`. La trace « BANC WEB : OUVERT/FERMÉ » est conservée, hors du chemin chaud. |
| M15 | Slider Kd borné à 10 vs `kKdMax = 20` | **appliquée** | `max="20"` (`tuner.cpp`). |
| M16 | Réarmement sans recentrage → panique si pieds > ~25° | **appliquée (doc seule)** | Paragraphe ajouté à `TEST_PROTOCOL.md` §5 : symptôme (« CHUTE » robot debout), cause (aucun `recenterNow()` à l'armement), consigne (MANUEL, ramener les pieds vers 0 aux flèches, `P:` ≈ 0). Comportement inchangé. |
| M17 | Ce que le sim ne modélise pas | **appliquée** | Docstring du sim : trame PWM 50 Hz (0-20 ms, échantillonneur-bloqueur), mort-zone SG90 (~5-10 µs ≈ 0,5-1°), pas de borne d'accélération, friction/3D/masse des pieds, retard forfaitaire 25 ms. Le commentaire faux de `tau_f` (« filtre complémentaire 0,25 s », §2 #9) est remplacé par « retard total de boucle, non justifié finement, le verdict en dépend » — valeur inchangée. |
| M18 | `Imu::calibrate()` : retour ignoré, 400 lectures = 60 échantillons | **appliquée** | `balance.cpp` : `if (!Imu::calibrate()) Serial.println(…)` (setup, hors chemin chaud), IMU conservée. `imu.cpp` : `delay(5)` entre lectures (≈ 200 Hz → 400 échantillons distincts en ~2,2 s), lectures via `readLive()` (les trames figées ne comptent pas). Commentaire `imu.h` : « ~300 ms » → « ~2 s ». |
| M19 | Reprise automatique après imuLost/rateLow | **appliquée (commentaire seul, rien changé)** | Bloc de commentaire à la déclaration de `s_imuLost`/`s_rateLow` : choix documenté, limite robot libre vs tenu, relais par le verrou de chute. |

Non retenu / hors liste (signalé, pas modifié) :
- **§2 #7 / M12 — throttling NVS qui saute l'écriture** : non demandé, non modifié. Conséquence
  à connaître : dans `handleGains()`, `setGains` → `setRecenterGains` → `setOutScale`
  appellent chacun `saveGains()` ; seul le premier écrit (fenêtre 1,5 s), donc Kpφ/Kv et
  désormais kOut ne sont persistés qu'au POST **suivant** (valeurs déjà en RAM). Fix
  recommandé inchangé : drapeau dirty + écriture au désarmement.
- **§2 #9 — valeur de `tau_f`** : commentaire corrigé (M17), valeur 25 ms conservée (pas dans
  la liste ; le verdict du sim en dépend, c'est écrit dans la docstring).
- `README.md:35` (« Gains validés par simulation ») et `TEST_PROTOCOL.md:3-4` (« gains
  sim-validés ») restent **faux** au vu de §1 #5 / M4 — hors de la liste « renvois périmés »,
  non touchés. À corriger par l'orchestrateur avec le prochain flash.
- `TEST_PROTOCOL.md` §4 et le tableau « Réglages rapides » gardent la logique « position »
  (buzz → ↓Kp ↑Kd) contredite par M8 ; non listés, non touchés.

### Compilation (sans upload)

`arduino-cli compile --fqbn esp32:esp32:esp32s3:USBMode=hwcdc,FlashSize=16M,PSRAM=opi`
+ les defines de `build.sh` (170×320, ST7789) : **0 erreur**, 1 046 902 o de flash (79 %),
50 916 o de RAM (15 %). Recompilation complète séparée (`--build-path /tmp`, `-Wall -Wextra`
effectifs) : **aucun avertissement dans les fichiers modifiés** ; seuls subsistent 3
`-Wformat-truncation` préexistants dans `ui.cpp:1057/1091/1150` (non touchés).

### Simulateur — AVANT / APRÈS (gains embarqués Kp25/Ki500/Kd0,5, `random.seed(42)`)

| Variante | AVANT (`2c64860`) | APRÈS (M1 M2 M3 M5 M10 M11) |
|---|---|---|
| défaut (cascade ON, Kv 3, k_out 1) | **0/6** — panic φ @0,41 s ×5, chute θ @0,35 s | **0/6** — chute θ @0,39-0,49 s ×6 |
| `--no-cascade` | **0/6** — chute θ @0,35-0,54 s | **0/6** — chute θ @0,43-0,90 s |
| k_out 3, Kv 0 (cascade neutralisée) | n/a (k_out non réglable) | **0/6** — panic φ @1,65 s (θ0 = 2°), 0,93 s (tapes) |
| `--sweep` (280 jeux × k_out {1,2,3}, 6/6 exigé) | 0 jeu (280 jeux, k_out 1 seul) | **0 jeu** (cascade Kv 3 : 280 × 3 à 0/6 ; `--no-cascade` : 0 jeu à 6/6) |

Tapes (poussée à t = 3 s) : avec les gains embarqués **aucune tape n'est atteinte**, avant
comme après (chute avant 0,5 s ; 1,65 s au mieux). Elles ne le sont que dans le balayage
étendu, **k_out = 3 et cascade neutralisée** (Kv = 0 ou `--no-cascade`) : meilleur jeu
2/6 avec les **3 tapes atteintes**, par ex. Kp25/Ki350/Kd1 → θ0 = 2° tenus 6 s (φfin +10°/−5°),
tapes → panic φ **0,1-0,2 s après la poussée** (3,10-3,20 s) : 0,4 rad/s consomme déjà les
±25 mm de course, ce que le protocole annonçait déjà comme limite physique. Histogramme
du balayage (Kv 0) : k_out 1 → 280 jeux à 0/6 ; k_out 2 → 13 jeux à 2/6 ; k_out 3 → 26 jeux
à 2/6. Avec la cascade à Kv = 3, **tout** panique φ en 0,2-0,4 s quel que soit k_out
(saturation Kv·RefMax, cf. M4-4) — la recommandation « Kv = 0 au banc » tient.

Lecture : les corrections n'améliorent pas le compte 6/6 des gains embarqués (le retard
forfaitaire de 25 ms les rend linéairement instables, §2 #9) ; elles changent ce que le
sim mesure : (i) les tapes deviennent atteignables (k_out 3), (ii) le cliquet de la
mort-zone est éliminé sur les jeux stables (M3, vérifié ci-dessus), (iii) le plafond
intégral n'écrête plus la raideur (M10 : 1,13 s → 1,65 s avant panic), (iv) le sim et le
firmware ont enfin les mêmes signes (M1, M2) et une physique de 19 % moins pessimiste
(M5). Le prochain pas côté sim n'est pas une recherche de gains mais la justification de
`tau_f` et la modélisation de la trame 50 Hz (M17).

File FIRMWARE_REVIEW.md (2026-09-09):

# Review firmware BalanceBot — 09/09/2026

> **MISE À JOUR 09/09 (nuit) — voir `STALL_ANALYSIS.md`.** Trois chantiers ont été
> menés après cette review : (1) **cadence** — cause racine trouvée et corrigée
> (auto-sleep du CST816 qui bloquait le bus I²C ~1 s : 21 chutes/60 s → 0) ;
> (2) **tactile** — miroir X (l'axe long du CST816 est inversé vs l'écran : sans
> lui, appuyer sur AVANT/GAUCHE armait le robot), rejet des trames poubelles,
> verrou d'appui au changement de mode ; (3) **visage AUTO** — 3 bloquants + 4
> importants de `FACE_REVIEW.md` corrigés. Banc final : `hz` min 199 (contrôle),
> 196 (visage), pire passage écran 7 ms, verdict OK. `interfaces.h` a gagné des
> champs de diagnostic de cadence (documentés dans `STALL_ANALYSIS.md §2`).

Périmètre : les 14 fichiers du sketch (`balance-bot/`, ~2 300 lignes) — `balance.cpp`,
`feet.cpp`, `imu.cpp`, `head.cpp`, `ui.cpp`, `tuner.cpp`, `battery.cpp`, le `.ino`,
`config.h`, `interfaces.h` et les en-têtes privés. Méthode : lecture intégrale, comparaison
avec le modèle validé en simulation (`sim/balancebot_sim.py`), puis **compile vérifiée**
(`arduino-cli`, FQBN/flags de `build.sh`) après correction — 78 % flash, 15 % RAM, 0 warning.

> La loi de commande n'a qu'UNE modification : le **signe de la cascade de
> recentrage** (faute n°12), démontré faux en simulation — le reste (PID, soft
> clamp, bornes, dt) est inchangé. Aucune re-simulation du PID n'est nécessaire
> pour les autres correctifs (garde-fous et précision de mesure uniquement).

---

## 1. Fautes corrigées (commit « review firmware »)

| # | Fichier | Faute | Correction |
|---|---|---|---|
| 1 | `config.h`, `feet.cpp`, `balance.cpp` | Butée dure des pieds recopiée en littéral `45.0f` dans **deux** fichiers : le soft clamp et la butée réelle peuvent diverger silencieusement (classe de bug déjà vue sur le châssis). | `#define FOOT_HARD_DEG 45.0f` dans `config.h`, source unique lue par les deux. |
| 2 | `balance.cpp` | **IMU muet non détecté** : `Imu::update()` était appelé en ignorant son retour. Bus I2C secoué (duponts volants) → l'angle se fige et le robot asservit sur une mesure morte jusqu'à la chute. | Compteur de trames perdues ; au-delà de 20 consécutives (~100 ms à 200 Hz) → `halt()`. Reprise automatique dès qu'une trame repasse (`s_imuLost`). |
| 3 | `balance.cpp` | **Servos de pieds non attachés** : `Feet::begin()` n'était pas vérifié. Servos absents → φ reste à 0, le robot « équilibre » des pieds morts. | Garde `if (!Feet::ready()) { halt(); return; }` avant toute logique d'asservissement. |
| 4 | `balance.cpp` | **Armement sur consigne héritée** : un doigt resté sur une flèche pendant que l'équilibre était coupé repartait à 100 à l'armement → bond du robot. | `setEnabled(true)` remet `cmdForward`/`cmdTurn` à zéro. |
| 5 | `battery.cpp` | **ADC brut non calibré** : `analogRead()` remis à l'échelle linéairement → 10-20 % d'erreur (le seuil 3,5 V n'a plus de sens). | `analogReadMilliVolts()` (courbe eFuse du S3). |
| 6 | `tuner.cpp` | **POST tronqué = gain à 0** : `arg().toFloat()` renvoie 0 pour `kp=` ou `kp=abc`, et `setGains()` recevait ce 0 → perte du terme P en pleine session de réglage. | Parsing strict `strtof` + vérification de fin de chaîne ; non numérique → `NAN` (gain inchangé). |
| 7 | `imu.cpp` | **Détection capteur incomplète** : le premier ACK sur 0x68 suffisait ; un autre esclave à cette adresse faisait échouer `WHO_AM_I` **sans essayer 0x69**. | Chaque adresse est testée complètement (présence **et** identité) avant d'abandonner. |
| 8 | `head.cpp` | **Ultrason bloquant 12 ms** (2,4 cycles de la boucle 200 Hz) pour une portée utile de 150 cm. | Timeout calculé depuis `US_MAX_CM` (8,7 ms + marge) — moins de temps volé à l'équilibre. |
| 9 | `head.cpp` | **Servos de tête réécrits 50×/s** à position identique → vibration/ronronnement SG90 pour rien. | Écriture uniquement au changement de position. |
| 10 | `ui.cpp` | **Touch en panne = écran mort** : `Ui::begin()` retournait `false` et `Ui::loop()` sortait, plus aucune télémétrie. | L'écran reste actif (télémétrie), les boutons sont inertes, bandeau rouge « TOUCH KO », statut sur le port série. |
| 11 | `.ino`, `config.h`, `feet.cpp`, `ui.cpp` | Commentaires périmés : « 4× SG90 (2 rotatifs roues…) », renvoi à `chassis/FIT_NOTES.md` (purgé), « ancien wheels.cpp », « roues au neutre ». | Réécrits (pieds en arc v3.1, `NOTES_v3.md`). |
| 12 | `balance.cpp` | **Signe de la cascade de recentrage inversé** : pour un pied parti en avant (φ > 0), la contribution au setpoint était négative, donc le PID commandait le pied… **vers l'avant** : le pied filait vers la butée au lieu de revenir (simulation : pied lâché à +20° → +37° en 0,3 s, puis panic). | Contribution inversée (`-kRecenterKv·(v_cible − φ̇)`), dérivation et preuve en commentaire. Les gains de la cascade restent à régler sur le robot (tuner). |
| 13 | `sim/balancebot_sim.py` | **Le simulateur ne modélisait pas le firmware** : ni cascade de recentrage, ni roulement exact (`ẍ = R·φ̈` au lieu de `R·(θ̈+φ̈)`), plus un amortissement artificiel `-0,5·θ̇`, et sa docstring affirmait des gains « validés » que son propre code invalide (0/6 scénarios). | Modèle physique exact, cascade portée à l'identique, docstring remplacée par l'état MESURÉ + mode `--sweep` / `--no-cascade`. |

## 1bis. Le point le plus important : la validation de la loi de commande ne tient plus

Ce n'est pas une ligne de code mais l'état du projet, et c'est ce qui doit guider le premier
test réel :

1. `sim/balancebot_sim.py` **n'a jamais modélisé la cascade de recentrage** (lot 2c) — son
   contrôleur était le PID seul. Le script qui avait « validé » la cascade n'est pas dans le
   dépôt (seul `sim/cascade_recenter.md`, sa docstring, a été committé) : ce résultat n'est
   pas rejouable.
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

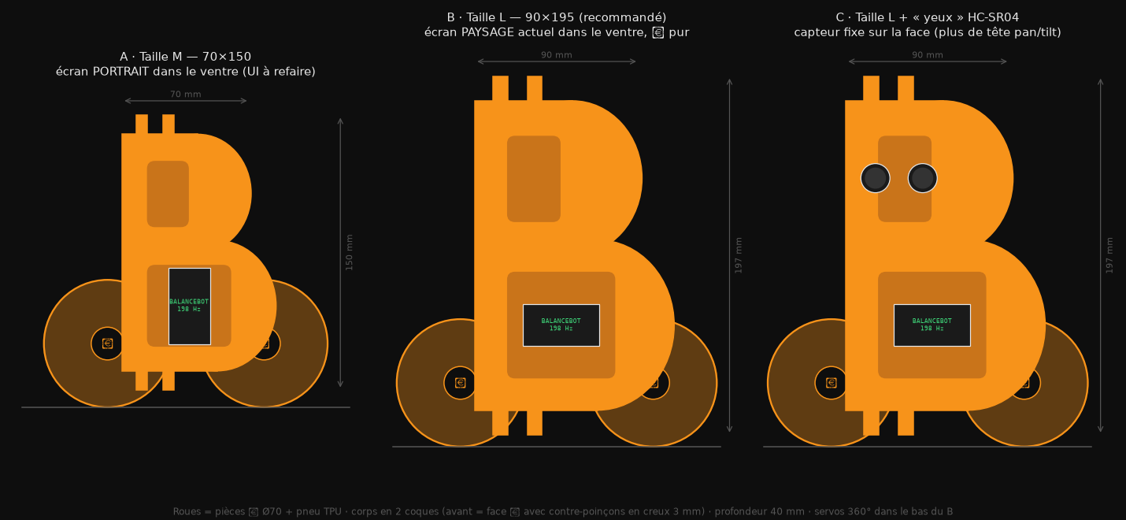
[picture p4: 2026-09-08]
concept_bitcoin_bot.png

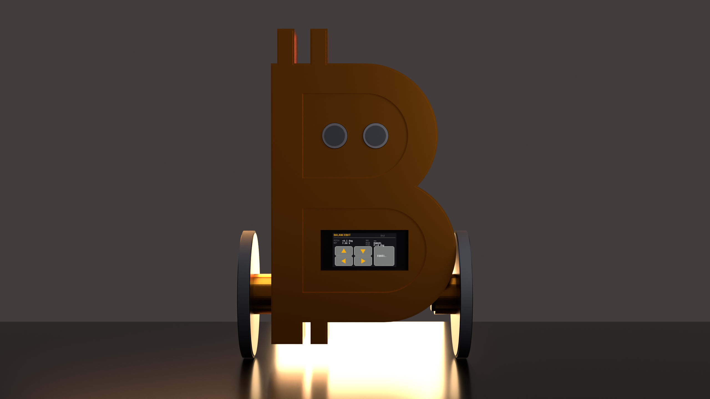
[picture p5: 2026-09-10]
chassis/render/hero_face.png

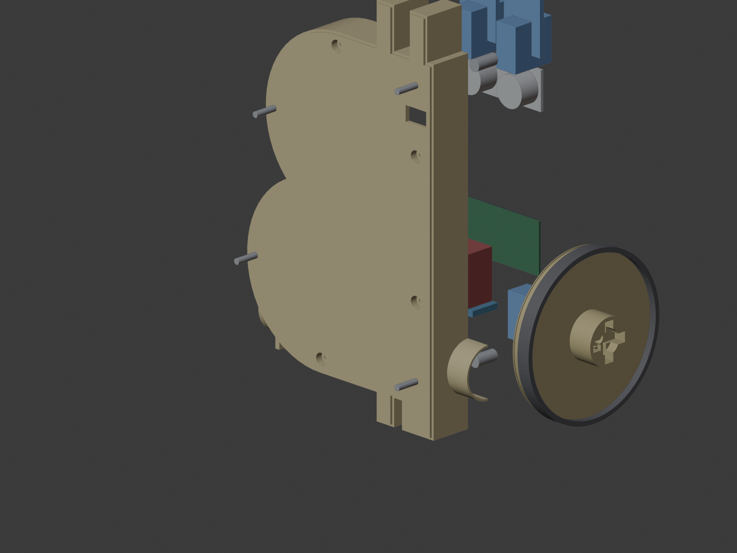
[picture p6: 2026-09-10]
chassis/render/interne_avant.png

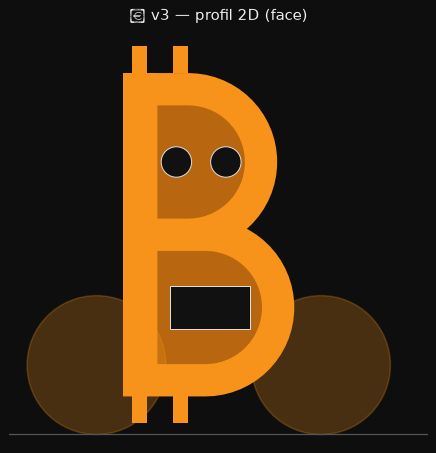
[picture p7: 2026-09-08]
chassis/v3_profile_check.png

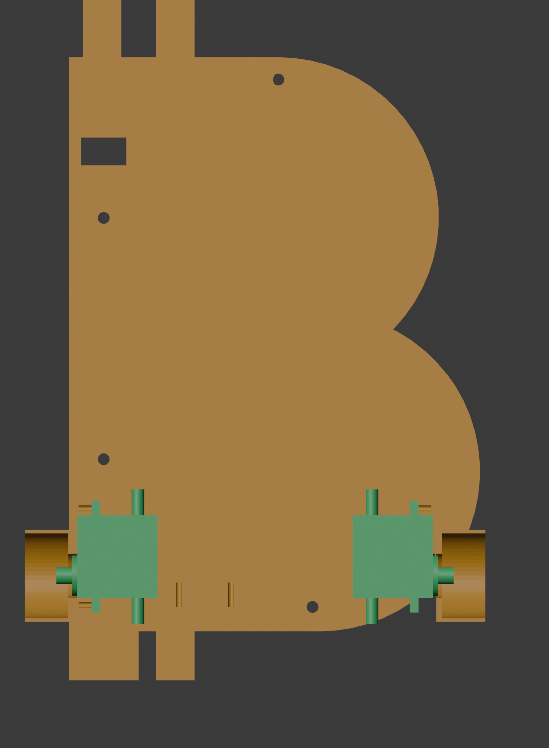
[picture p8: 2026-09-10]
chassis/review/servo_view.png

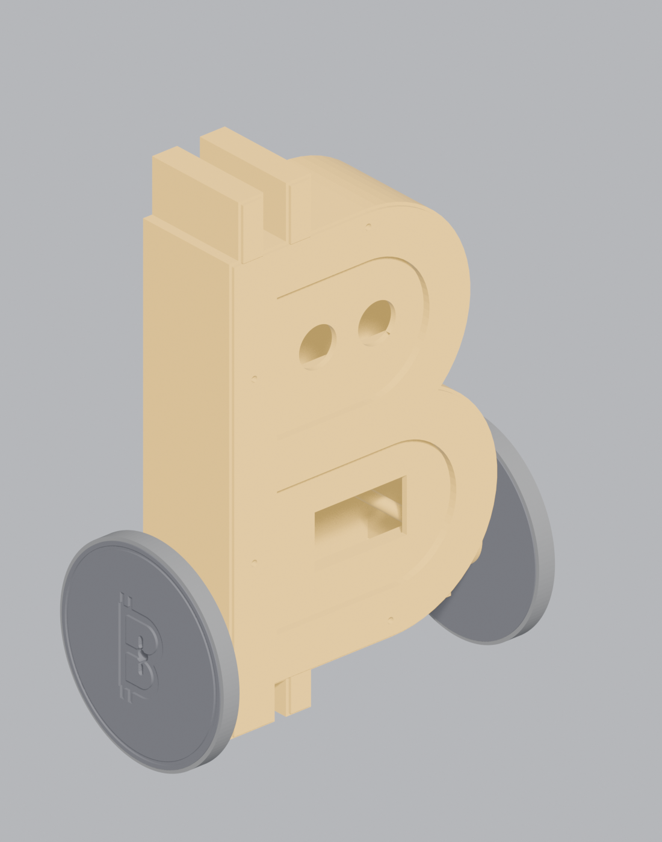
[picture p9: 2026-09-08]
chassis/v3/preview_iso.png

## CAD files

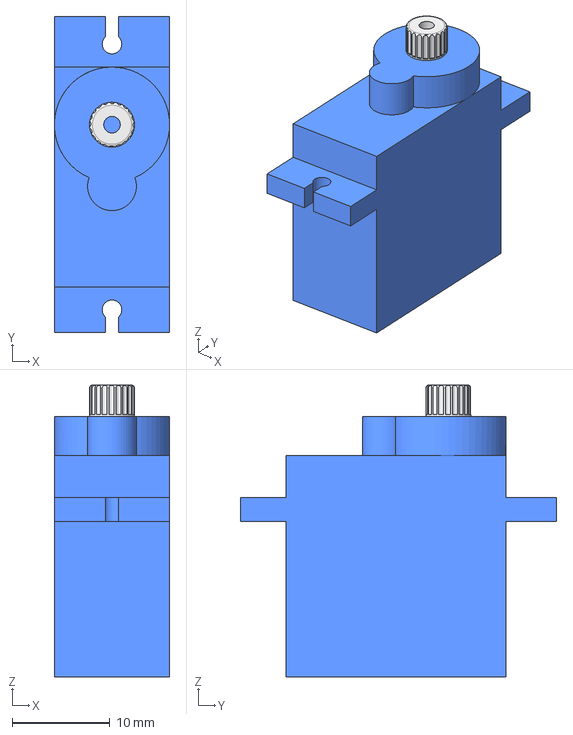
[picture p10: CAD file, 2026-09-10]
chassis/assets/servo/Servo-sg90.step
11.8 x 32.4 x 29.9 mm

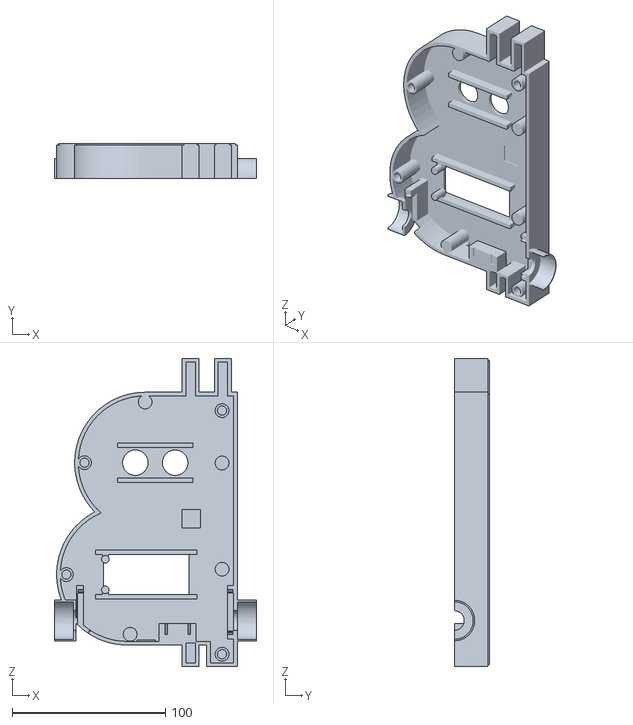
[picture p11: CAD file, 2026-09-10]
chassis/v3/b_front.stl
132.1 x 23.0 x 201.0

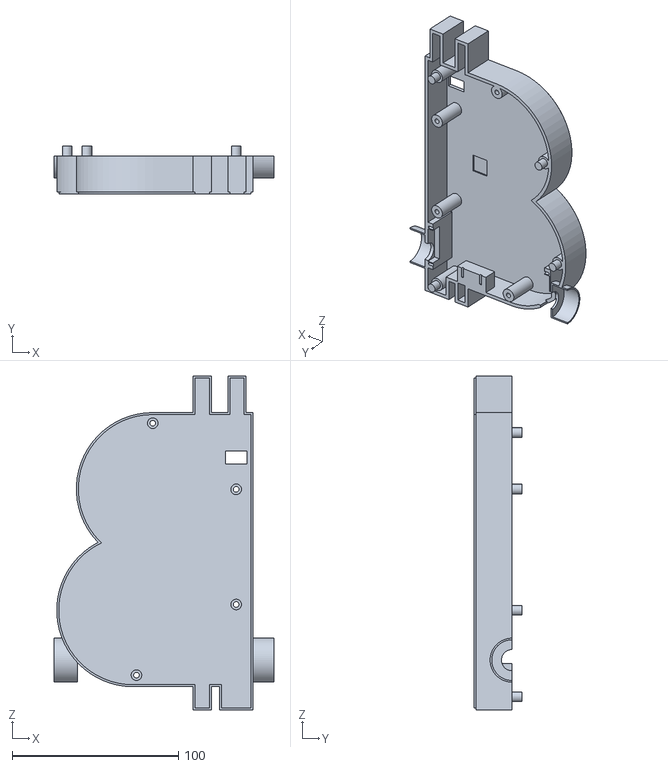
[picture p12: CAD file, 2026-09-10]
chassis/v3/b_back.stl
132.1 x 29.0 x 201.0

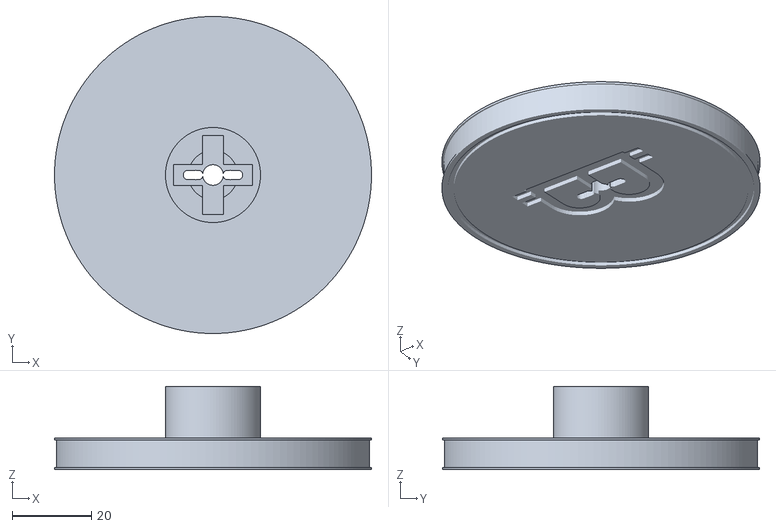
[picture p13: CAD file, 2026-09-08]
chassis/v3/coin_wheel.stl
80.0 x 80.0 x 21.0

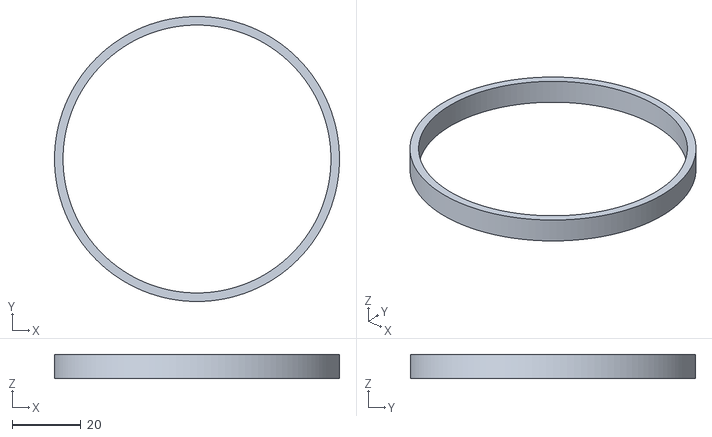
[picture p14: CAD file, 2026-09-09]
export/v31/plateT_tire2.stl
83.0 x 83.0 x 7.00

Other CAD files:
export/v31/plate1_b_front.stl
export/v31/plate2_b_back.stl
chassis/v3/coin_tire.stl
export/v31/plateT_tire1.stl
export/v31/plateR_wheel2.stl
export/v31/plateR_wheel1.stl
chassis/assets/servo/Servo-SG90.stl

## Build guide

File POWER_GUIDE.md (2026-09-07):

# BalanceBot — Guide d'alimentation des servos (LOT 3)

**Règle d'or : les servos ne tirent JAMAIS sur le 3V3 ou le 5V de la carte.**
Un SG90 en mouvement/blocage tire 200-700 mA (pic ~1 A). Le régulateur USB
de la carte s'effondre → brownout → reboot (déjà observé au test du 06/09).
Les servos ont leur PROPRE rail d'alim, avec la MASSE commune à la carte.

## Consommation réelle
- 2 servos de pieds (équilibre, mouvement quasi continu) : 100-400 mA
- + 2 servos de tête (balayage démo) : +100-200 mA
- Total : ~0,5-1 A en crête → rail 5V/2A+ recommandé

## Options (de la plus simple à la plus propre)

### Option A — Power bank USB (test immédiat, 0 € si tu en as un)
```
Power bank 5V ──┬── servo pied G (rouge) ──┐
                ├── servo pied D (rouge) ──┤  2-3 servos max
                └── servo tête (rouge) ────┘
Toutes les MASSE (marron) ──┐
                            ├──→ GND de la carte (INDISPENSABLE)
                            └──→ GND du power bank (via la prise)
Signaux (orange) ──→ GPIO 1/2/3/10 de la carte (aucun courant)
```
⚠️ Power banks qui se coupent à faible charge : si les servos tirent peu
(robot immobile), certains power banks se mettent en veille après ~30 s.
Solution : garder un petit mouvement continu OU utiliser l'option B/C.

### Option B — 4× piles AA (1,5V ×4 = 6V) ou 1× pile 9V + régulateur
- 4× AA alcalines : 6V nominal — dans la plage SG90 (4,8-6V), OK sans
  régulateur, ~1,5-2 A dispo. Simple et sûr. À jeter/charger ensuite.
- 1× pile 9V + module buck MP1584/XL4015 réglé à 5,0V : plus propre,
  ~0,5 A utile seulement (les piles 9V n'aiment pas les forts courants).

### Option C — Module buck 5V/3A + alim secteur (la meilleure pour les tests)
```
Chargeur USB-C 5V/2A+ ou alim 7-12V
   → module buck réglé à 5,0-5,5V (MP1584 ~2 €, XL4015 ~4 €)
   → rail servos (+ condos 470-1000 µF sur le rail, près des servos)
```
Les condos encaissent les pics de courant des servos (le module buck seul
peut avoir un temps de réponse trop lent).

### Option D — Batterie LiPo 2S (7,4V) + BEC 5V/3A (pour le robot autonome)
C'est l'option « produit fini » : le robot sans fil. La carte accepte la
batterie sur son connecteur (PIN_BAT_VOLT GPIO4 = mesure), les servos sur
le BEC. À faire APRÈS les tests USB.

## Câblage type (4 servos + carte)
```
[Alim 5V rail] ──────┬─────┬─────┬─────┐
                     R     R     R     R      (rouges servos 1,2,3,10)
[GND commun] ────────┬─────┬─────┬─────┬──── GND carte
                     N     N     N     N      (marron servos)
Signaux : S1→GPIO1  S2→GPIO2  S3→GPIO3  S10→GPIO10
+ 470-1000 µF entre rail 5V et GND, AU PLUS PRÈS des servos
```

## Checklist avant d'armer l'équilibre
- [ ] Masse commune carte ↔ alim servos (sans ça : comportements fous)
- [ ] Jamais de fil rouge sur 3V3
- [ ] Carte alimentée en USB (données + 5V logique) — les 2 masses reliées
- [ ] Test : activer la démo (flèches) → les pieds bougent SANS reboot
- [ ] Si reboot : alim servos insuffisante → Option C (buck + condos)

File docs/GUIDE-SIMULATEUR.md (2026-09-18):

# Guide du simulateur

Ce simulateur rejoue **la même physique et le même correcteur que le robot**, mais il
existe surtout pour une chose : **pouvoir régler, casser et comprendre sans risquer le
robot**. La règle du projet est simple, et elle vaut pour tout ce qui suit :

> **Le simulateur et le firmware doivent dire la même chose.** Toute divergence est un bug
> des deux côtés à la fois.

Deux façons de l'ouvrir — aucune installation, aucun serveur :

- **en ligne** : <https://silexperience210.github.io/balance-bot/simulateur.html>
- **en local** : télécharge `simulateur.html` et ouvre-le par double-clic (tout est dans le
  fichier : le moteur, les vraies pièces 3D, le visage).

---

## 1. La vue 3D

| Geste | Effet |
|---|---|
| glisser | tourner autour du robot |
| molette | zoomer |
| clic droit | déplacer la vue |

Le robot, l'obstacle, le faisceau et les capteurs sont des modèles **des vraies pièces**
(`chassis/v3/`). Les coques sont à la couleur du produit.

## 2. Faire tourner la simulation

- **`RUN`** lance ou reprend, **`PAUSE`** arrête sur place, **`RESET`** remet le scénario à
  son état initial.
- **Vitesse de lecture** : `0,5×` · `1×` · `2×`. Mets **0,5× pour regarder une chute** :
  c'est là qu'on voit *pourquoi* le robot tombe, pas seulement qu'il tombe.
- **Scénarios** : `θ0=2° propre` (départ penché de 2°, sans bruit), `θ0=2° bruit`,
  `θ0=5° bruit` (avec le bruit du capteur réel), et trois `tape 0,4 / 0,8 / 1,2 rad/s`
  (une poussée franche, à un instant donné — la façon la plus parlante de tester la
  robustesse).
- La bannière en haut de la scène donne le verdict en direct : **ÉQUILIBRE OK**, chute,
  ou dépassement.

## 3. Les gains

- **Jeu de gains** : deux préréglages.
  - `jeu qui TIENT (5/6 · Kv=0)` — le robot reste debout dans 5 scénarios sur 6. **C'est le
    réglage par défaut.**
  - `gains EMBARQUÉS (il tombe)` — exactement ce qui est flashé dans le robot aujourd'hui,
    qui ne tient pas encore. Utile pour voir l'écart à combler.
- **Les cinq curseurs** : `Kp` (proportionnel — la raideur), `Ki` (intégral — rattrape la
  dérive lente ; c'est lui qui manque quand le robot s'incline doucement), `Kd`
  (dérivé — amortit), `Kpφ` et `Kv` (la cascade interne de vitesse).
- Repère utile : la condition de stabilité demande **Ki > g/R ≈ 300**. Un `Ki` trop faible
  est *l'erreur classique* : le robot paraît tenir puis se couche lentement, sans que rien
  ne l'ait poussé.

## 4. Le visage

`auto — suit l'état simulé` laisse le visage exprimer ce que fait vraiment le robot
(équilibre, chute, batterie faible). Les autres entrées forcent une expression : `calme`,
`penché`, `méfiant`, `énervé`, `surpris`, `content`, `chute`. C'est le même dessin que
l'écran du robot (table `faceStyle()` du firmware).

## 5. Le capteur à ultrasons

Le robot a un **HC-SR04** ; le simulateur le reproduit **au comportement près**, y compris
ses défauts :

- **Obstacle** : un curseur de **5 à 200 cm** place une plaque devant le robot. Le chiffre
  affiché est la position du **centre** de la plaque depuis l'axe des roues ; la distance
  mesurée, elle, part de la **sonde** (≈ 4 cm plus en avant). Une lecture plus petite que le
  curseur est donc **normale**.
- **`ECHO câblé`** : décoche-la pour simuler un capteur **absent ou mal câblé**. C'est
  exactement ce qui arrive sur un vrai montage quand la ligne ECHO n'est pas branchée.
- **Le faisceau** : 🟢 obstacle vu · 🔴 **alerte** (moins de 25 cm) · gris discret : rien
  dans la portée.
- **Télémétrie** : distance lissée, état (rien · obstacle · **ralenti < 60 cm** · **ALERTE
  < 25 cm**), **cadence de mesure** (200 ms ; elle passe à **1 s après trois échecs
  consécutifs** — sur le vrai robot la mesure bloque le processeur, on l'espace donc quand
  il n'y a rien à voir), échecs consécutifs, position de la tête, l'angle sous lequel
  l'obstacle a été vu et le **côté** qui en découle, la **phase d'évitement** et la
  **consigne imposée** au déplacement.
- **La tête** : robot au sol elle balaie tout son débattement (0…180° / 20…90°) ; **en
  équilibre elle balaie ±30° autour du centre** (`HEAD_BALANCE_SWEEP_DEG`), tilt au centre —
  c'est ce balayage qui donne un côté à l'obstacle. Elle n'est pas visible en 3D (le
  châssis n'a pas de tête séparée) et, comme sur le châssis v3 où le HC-SR04 est fixé au
  corps, **elle ne tourne pas le faisceau** : la mesure suit le corps, pas le pan.

## 5 bis. L'évitement d'obstacle (miroir de `head.cpp` → `balance.cpp`)

Depuis le firmware `10044c0`, le robot **réagit** à l'obstacle — et le simulateur fait la
même chose, avec les mêmes constantes de `config.h`, **sans jamais toucher à l'équilibre** :
l'évitement n'agit que sur les **consignes de déplacement** (les flèches de l'écran), avant
leur lissage, jamais sur le PID ni sur les roues.

| Phase | Condition | Consigne imposée |
|---|---|---|
| LIBRE | rien sous 60 cm | avance ≤ 100 (aucune) |
| RALENTI | 25 ≤ distance < 60 cm (`US_SLOW_CM`) | avance plafonnée à **40** |
| RECUL + PIVOT | distance < 25 cm (`US_STOP_CM`) | **recul à −20** (≈ −1,2° de consigne) et **pivot ±40** du côté libre |
| PIVOT seul | recul épuisé (1,5 s, `AVOID_BACK_MAX_MS`), obstacle toujours là | avance 0, pivot conservé |
| reprise | distance > 35 cm (`US_CLEAR_CM`, hystérésis) ou plus d'écho | retour LIBRE / RALENTI |

Le **côté** : le pan de la tête à l'instant où l'obstacle est passé sous 25 cm (pan > 100°
→ obstacle « à droite » (+1) → pivot à gauche (−40) ; pan < 80° → l'inverse ; entre les
deux « en face » → côté par défaut). Il est **verrouillé** pour toute la manœuvre. Le sens
mécanique n'est pas connu du firmware (`AVOID_TURN_SIGN`) : dans le simulateur, un pivot
négatif tourne vers la gauche (−Z).

**Le panneau « Déplacement »** reproduit les flèches de l'UI du robot (`cmdForward`,
`cmdTurn`, ±100) : avancer = incliner la consigne d'angle de 0,06° par unité, tourner =
différentiel de roues (0,30 par unité), les deux lissés à 200 unités/s — exactement
`balance.cpp`. Le lacet ψ et la position au sol sont intégrés depuis la différence de
vitesse des deux roues sur la voie (139 mm) : c'est une grandeur du **simulateur** (pour
voir le pivot), le robot n'a ni cap ni odométrie.

**Pour le voir** : bouton **`Démo évitement`** (consignes à 0, plaque à 25 cm, RUN). Dès la
première mesure (0,2 s) le robot **recule et pivote** ; à 1,7 s il ne recule plus et pivote
seul ; **à 1,9 s il tombe**. Ce n'est pas un bug du simulateur : avec le jeu de gains qui
tient (Kv = 0) **rien ne borne la vitesse** — un recul à −20 est une accélération constante,
et 1,5 s suffisent à saturer la roue (250 °/s), après quoi le pendule n'est plus tenu. Même
chose pour toute consigne d'avance : le robot **accélère sans fin** puis chute (1 à 3 s
selon la consigne). Le ralentissement à 60 cm se voit donc dans la consigne effective (60 →
40, θ_ref 3,6° → 2,4°), pas dans une marche durable. C'est ce que dit le modèle du
firmware actuel ; le robot réel a des servos plus rapides (la saturation viendrait plus
tard), mais pas de boucle de vitesse non plus.

**Géométrie** : la plaque fait 10 mm × 10 cm de large ; le capteur est un **lobe de ±15°**
(datasheet HC-SR04), pas un rayon — la distance mesurée est celle du point de la face le
plus proche à l'intérieur du lobe, donc la plaque reste vue pendant le pivot tant qu'elle
n'en sort pas. Un rayon fin la perdrait à ~11° de lacet et écourterait la manœuvre.

## 6. Les animations

Un sélecteur avec `Aucune`, `Hochement`, `Regard gauche-droite`, `Sursaut` (un coup,
relançable), `Danse`, plus **`Rejouer`**. Ce sont des animations **cosmétiques** : elles
jouent sur l'image, jamais sur la physique. Le robot continue de tenir exactement comme
avant, et `Aucune` redonne l'image strictement identique. C'est volontaire : on veut
pouvoir filmer le robot sans fausser la moindre mesure.

## 7. Donner des fonctions au robot (le moteur d'effets)

C'est la partie puissante. En bas de page, l'éditeur **« EFFETS SECONDAIRES (HOOK
MOTEUR) »** accepte du JavaScript, que tu appliques avec **`Appliquer`**. Ta fonction est
appelée **200 fois par seconde**, **après** la physique de chaque pas :

```javascript
function customEffects(t, state, dt) {
  // t  : temps simulé en secondes
  // dt : pas de temps (0,005 s à 200 Hz)
  // state : l'état du robot, EN DEGRÉS
}
```

### Ce que tu peux modifier et lire

| Écriture (ça agit) | Lecture seule (ça informe) |
|---|---|
| `theta`, `thetaDot` (assiette et sa vitesse) | `t` (temps simulé) |
| `phi`, `phiDot`, `phiCmd` (roue : position, vitesse, consigne) | `pidOut` (sortie du correcteur) |
| `integ` (terme intégral) | `setpoint`, `footVelCmd` (cascade interne) |
| `pitchFilt`, `rateFilt` (mesures **filtrées** — c'est ce que voit le correcteur) | `noise`, `verdict`, `fallen`, `panicked`, `done`, `k`, `tmax` |
| `recenterVel`, `footVelFilt` | |

Écrire dans `pitchFilt` plutôt que dans `theta` simule un **défaut de capteur**, pas une
poussée : le correcteur croit alors à une inclinaison qui n'existe pas — c'est ainsi qu'on
teste une panne de mesure.

### Exemples prêts à coller

Les valeurs indiquées après la flèche sont **mesurées dans le simulateur**, sur le scénario
`θ0=2° propre` avec le jeu de gains qui tient — pas des estimations.

```javascript
// 1. Vent constant : pousse le corps en continu
//    → tient à 10 °/s² ; tombe à 3,1 s à 30, à 1,8 s à 60, à 1,1 s à 120
function customEffects(t, state, dt) { state.thetaDot += 10 * dt; }

// 2. Sol glissant : amortit l'oscillation — il tient mieux, pas moins bien
function customEffects(t, state, dt) { state.thetaDot *= (1 - 0.5 * dt); }

// 3. Capteur qui dérive de +0,5° : le correcteur se bat contre un fantôme
//    → CHUTE en ~1,2 s. C'est l'exemple le plus parlant : une erreur de mesure
//      tue le robot aussi sûrement qu'une poussée.
function customEffects(t, state, dt) { state.pitchFilt += 0.5; }

// 4. Tape à t = 2 s (une impulsion, une seule)
//    → encaisse 25 °/s sans broncher ; tombe à 60 °/s (2,8 s) et 120 °/s (2,3 s)
function customEffects(t, state, dt) {
  if (t >= 2 && t < 2 + dt) state.thetaDot += 25;   // °/s
}

// 5. Sol en pente : le robot est incliné en permanence
//    → tient à 3 °/s ; monte la valeur pour trouver le décrochage
function customEffects(t, state, dt) { state.theta += 3 * dt; }

// 6. Servo paresseux : la roue ne suit la consigne qu'à moitié
//    → CHUTE en ~0,5 s : le robot perd son autorité de correction
function customEffects(t, state, dt) { state.phiDot *= 0.5; }
```

### Les 6 presets (boutons)

Au-dessus de l'éditeur, six boutons reprennent **exactement** les exemples ci-dessus, avec
le résultat **mesuré** affiché à côté (sur `θ0=2° propre`, jeu qui tient) :

| Preset | Attendu (mesuré) |
|---|---|
| **Vent constant** (`thetaDot += 10·dt`) | tient à 10 °/s² ; tombe à 3,1 s à 30 |
| **Sol glissant** (`thetaDot *= 1 − 0,5·dt`) | tient — l'amortissement aide |
| **Dérive capteur +0,5°** (`pitchFilt += 0.5`) | **chute en ~1,2 s** |
| **Tape à t = 2 s** (`thetaDot += 25`) | encaisse 25 °/s ; tombe à 60 |
| **Sol en pente** (`theta += 3·dt`) | tient à 3 °/s |
| **Servo paresseux** (`phiDot *= 0.5`) | **chute en ~0,5 s** |

Un clic **remplit l'éditeur, applique l'effet et relance** le scénario courant — tu vois le
résultat immédiatement, à comparer avec l'attendu affiché. Le preset ne **verrouille** rien :
le code reste dans l'éditeur, tu peux le modifier à la main (monter le vent à 30, changer
l'instant de la tape…) puis recliquer **`Appliquer`**.

### Les garde-fous

- Le cœur physique **n'est pas modifiable** : le hook est la **seule porte d'injection**.
  Tu ne peux donc pas « tricher » — ni sur le modèle du robot, ni sur le correcteur.
- Une faute de syntaxe s'affiche **sous l'éditeur**, sans planter la page.
- **`Réinitialiser le code`** enlève ton effet et remet le modèle nominal.
- Pour comparer proprement : lance un scénario **sans** effet, note le verdict, applique
  l'effet, relance le **même scénario**. C'est comme ça qu'on découvre qu'un réglage est
  fragile. Pour comparer deux **jeux de gains**, utilise directement la comparaison A/B
  (§7 bis).

## 7 bis. Comparer deux jeux de gains (A/B)

Le panneau **« COMPARAISON A/B (DEUX JEUX DE GAINS) »**, sous l'éditeur, fait tourner **deux
instances fraîches du moteur en parallèle** — la physique n'est pas dupliquée, elle est
instanciée deux fois (`BalanceEngine.create()`).

- **A** et **B** ont chacun leurs gains (`Kp`, `Ki`, `Kd`, `Kpφ`, `Kv`, `k_out`, cascade),
  pré-remplis par un sélecteur (A = jeu qui tient, B = gains embarqués) mais **modifiables
  à la main** champ par champ.
- **Scénario** : le même pour les deux, choisi dans la liste.
- **`Lancer A/B`** rejoue le scénario hors ligne (quelques millisecondes) et affiche côte à
  côte : verdict (**tient** / chute), **temps de chute**, **θ final**, puis un résumé
  (« A TIENT, B tombe → A meilleur »), et les **courbes d'assiette θ(t) superposées**
  (A en orange, B en bleu ; les pointillés rouges marquent le seuil de chute ±45°).

**Comparaison équitable, garantie et affichée** : même graine (42), même scénario, même état
initial, même effet secondaire éventuel (le dernier code « Appliquer » de l'éditeur est
rejoué, recompilé à neuf, sur les **deux** instances) — **seuls les gains changent**. La
note sous le bouton rappelle ces conditions à chaque lancement.

## 8. Ce que le simulateur ne fait pas

Autant le dire franchement, pour ne pas se fier à une simulation au-delà de ce qu'elle
vaut :

- **la tête pan/tilt n'est pas visible** : le châssis n'a pas de tête séparée (c'est le
  corps entier), donc l'orientation de la tête est simulée et affichée, mais pas montrée
  en 3D ;
- le simulateur reproduit la **cadence** des mesures, mais pas le **temps processeur volé**
  par la mesure ultrason (sur le robot, la mesure bloque la boucle d'équilibre jusqu'à
  9,5 ms) ;
- la mesure de distance est **horizontale** : un obstacle très bas ou très haut ne serait
  pas distingué ;
- **pas de collision** : le firmware **réagit** à l'obstacle (recul, pivot — §5 bis), mais
  si une consigne d'avance ou l'élan l'emporte, le robot peut traverser la plaque et rouler
  au-delà, rien ne l'arrête physiquement. La distance devient simplement « pas d'écho »
  (−1) une fois la plaque dépassée ;
- **le lacet est cinématique** : le pivot vient de la différence de vitesse des roues, sans
  inertie de lacet ni glissement, et le robot n'a ni cap ni odométrie réels pour le mesurer ;
- après une chute, la simulation **s'arrête** (elle ne rejoue pas le robot à terre) ;
- les frottements, le jeu mécanique, la souplesse des servos et l'usure **ne sont pas
  modélisés** : si le robot réel se comporte moins bien que la simulation, cherche d'abord
  de ce côté.

---

*Ce guide décrit le simulateur du dépôt. Si tu changes une constante du firmware
(`balance-bot/config.h`, `head.cpp`, `balance.cpp`), répercute-la ici **et** dans
`sim/web/ultrason.js` / `sim/web/engine.js` / `sim/balancebot_sim.py` : c'est la règle d'or.*

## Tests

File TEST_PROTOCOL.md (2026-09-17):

# BalanceBot — Protocole de test réel (premier essai debout)

Firmware : commit 87758d0 (Lot 1 bugs + Lot 2 feet.cpp + Lot 2b gains
sim-validés Kp25/Ki500/Kd0.5). À faire dans l'ordre, SANS brûler d'étapes.

## Prérequis matériel

- [ ] T-Display S3 Touch flashé (./build.sh) branché en USB
- [ ] **Alimentation séparée 5-6V pour les servos** (Lot 3) : les servos ne
      doivent JAMAIS tirer sur le 3V3/5V de la carte → brownout → reboot.
      Minimum : power bank 5V + GND commun. Même pour un seul servo.
- [ ] 2× SG90 + 2× foot_arc imprimés, palonnier calé (chassis/NOTES_v3.md, § Montage)
- [ ] MPU6050 monté sur son piédestal (fils fixes, plus de duponts volants)
- [ ] Table lisse, dégagée, ~1 m² — et un matelas/oreiller derrière le robot
      pour les premières chutes (elles arriveront)

## Étapes (chacune validée avant la suivante)

### 1. Boot et neutre (sans équilibre)
Brancher. Écran : « BALANCEBOT », pitch qui VIT, « USB » en batterie,
`P:` affiche l'angle pied (0 au repos).
**Vérifier** : les 2 pieds sont au neutre — milieu de l'arc pile sous l'axe,
robot visuellement droit. Si décalé : caler le palonnier (4 positions à 90°)
puis trims `kTrimDegL/R` dans feet.cpp.

### 2. Mode démo (flèches de l'UI, équilibre OFF)
Toucher AVANT/ARRIÈRE : les pieds roulent doucement ±15° max. GAUCHE/DROITE :
différentiel. **Vérifier** : les 2 pieds bougent en miroir dans le bon sens.
Si un pied part à l'envers : inverser `kDirL` ou `kDirR` (feet.cpp) — ou
tourner le palonnier de 180° (plus simple).

### 3. Signe du câblage (CRITIQUE — à faire robot tenu, couché ou sur son dos)
Poser le robot sur le dos (pieds en l'air, libres). Activer EQUIL. Incliner
le corps vers l'avant de ~10° à la main :
- **Bon signe** : les pieds partent VERS L'AVANT (pour rattraper la chute)
- **Mauvais signe** : les pieds partent en arrière → couper STOP immédiatement,
  inverser le signe (voir note ci-dessous)
Note : « avant » = le sens où le haut du robot penche.

Avant tout, vérifier l'ÉCRAN à l'étape 1 : pencher le robot vers l'avant doit
faire MONTER le pitch affiché (convention `pitch > 0 = penche vers l'avant`).
- Si le pitch affiché part dans le mauvais sens, l'IMU est monté à l'envers :
  inverser **les DEUX** constantes d'imu.cpp, `kAccelPitchSign` ET
  `kGyroPitchSign` (section RÉGLAGE MÉCANIQUE, ligne ~53). N'en inverser
  qu'une seule casse le filtre complémentaire (le gyro intègre à l'envers et
  l'accéléromètre le rattrape en permanence) : l'angle devient faux et
  traînard, pas seulement inversé.
- Si le pitch affiché est bon mais que les pieds partent en arrière, ce n'est
  PAS un problème de câblage : c'est le signe de la boucle (`out = -s_pid…`
  dans balance.cpp, bloc « SIGNE DE LA CONTRE-RÉACTION »). Ne pas le
  compenser dans imu.cpp — l'inversion de l'IMU inverserait aussi les flèches
  AVANT/ARRIÈRE de l'UI et le sens du recentrage.
Ne pas toucher aux servos si le signe est le même sur les deux pieds (le sens
de chaque pied se valide seul à l'étape 2, via kDirL / kDirR).

### 4. Équilibre tenu (robot maintenu)
Tenir le robot droit à la main (pieds au sol), activer EQUIL. Sentir les
pieds qui « vivent » sous les doigts (micro-ajustements). Incliner
doucement de ±5° : le robot doit pousser pour se redresser. Relâcher
progressivement en gardant les mains prêtes à rattraper.
- Oscillation rapide (buzz) → Kd trop faible OU Kp trop fort
- Mou mou / tombe lentement → Kp/Ki trop faibles
- Chute d'un côté constant → neutre décalé (trims) ou signe

### 5. Pose libre (premier lâcher)
Le robot tenu droit, le poser, attendre qu'il soit stable 1-2 s (le pitch
doit être ~0), puis lâcher doucement en retirant les mains vers le bas.
S'il part en avant ou en arrière : il « court » — c'est la cascade de
recentrage qui doit le ramener (si ça ne suffit pas, c'est le sujet du
prochain réglage, PAS un bug).

**Faire ce premier lâcher avec la cascade DÉSARMÉE** : dans le tuner web,
mettre Kpφ = 0 et Kv = 0. On valide d'abord le PID seul (le robot tient
debout mais dérive et finit en butée — c'est normal). Ensuite seulement,
monter Kv à 1 puis 3, et Kpφ à 0.4 puis 0.8. Raison : `Kv·(v_cible − φ̇)` est
borné à ±6°, soit autant que le plein gaz des flèches — à Kv = 3 il sature
dès 2 °/s d'écart de vitesse et peut injecter une assiette de consigne en
créneau. Ce point n'a jamais tourné sur du matériel réel, et le **signe** de
la boucle interne n'est pas tranché (REVIEW_CLAUDE.md M1) : Kv = 0 d'abord.

**Réarmement après un STOP — sans recentrage (à connaître, REVIEW_CLAUDE.md
M16)** : après STOP, les pieds restent où ils étaient (voulu : un retour au
neutre ferait basculer un robot debout). À l'armement suivant, aucun
recentrage automatique n'a lieu — seul le chemin « chute, puis 700 ms tenu
droit » ramène les pieds à 0. Si les pieds ont été laissés au-delà de ~25°, le
premier transitoire franchit la garde `kFootPanicDeg = 35°` et l'écran affiche
« CHUTE » alors que le robot est debout. **Avant d'armer : passer en MANUEL et
ramener les pieds vers 0 aux flèches** (l'écran `P:` doit lire ~0 ; au-delà de
±15° la démo n'autorise que le retour vers 0). Comportement inchangé,
documenté ici.

## Réglages rapides (constantes, balance.cpp)
| Symptôme | Constante |
|---|---|
| Buzz / oscillation rapide | ↓ kKp (25→15), ↑ kKd (0.5→1.0) |
| Tombe mollement | ↑ kKp (25→40), ↑ kKi (500→700) |
| Dérive avant/arrière constante | kTrimDegL/R (feet.cpp) ou neutre palonnier |
| Recentrage trop lent | ↑ Kpφ (tuner web, 0→0.8), puis ↑ Kv (0→3.0) |
| Robot qui « bat » à ±6° d'assiette | Kv trop fort : le redescendre à 0 |
| Robot complet (tête + mât montés, CoM > 100 mm) | Essayer Kp 40, Ki 600, Kd 1.5 (sim : gains v1 tiennent h ≤ 100 mm) |

## Limites connues (à ne pas prendre pour des bugs)
- **Mobilité ~2,5 cm max** (simulé) : le robot est un BALANCIER STATIQUE.
  Les flèches AVANT/ARRIÈRE en mode équilibre le feront avancer de 1-2 cm
  puis il se recentrera — au-delà, le pied tape sa butée et il tombe.
  C'est la physique des arcs ±45° sans boucle de vitesse. Ne pas insister.
- Course du pied ±45° → une grosse tape fait « courir » le robot puis
  tomber (physique, pas un défaut de gains)
- Le recentrage est volontairement TRÈS doux pour le premier test
- 200 Hz de boucle, mais le SG90 ne prend une consigne que toutes les 20 ms
- Sans alim séparée, les servos font rebooter la carte (brownout)

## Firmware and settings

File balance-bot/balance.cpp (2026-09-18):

// ═══════════════════════════════════════════════════════════════════
// BalanceBot — module A · boucle d'équilibre (API publique Balance::)
//
// Pendule inversé : le robot reste debout en déplaçant son point
// d'appui sous son centre de gravité. Il penche vers l'avant ⇒ les
// pieds roulent vers l'avant pour « rattraper » la chute, et
// réciproquement.
//
//   pitch (IMU) ──► erreur = consigne − pitch ──► PID ──► vitesse ROUE
//                                        ▲                    │
//                    cmdForward (UI) ────┘                    ▼
//                    cmdTurn    (UI) ─────► différentiel   Feet:: (vitesse)
//                    évitement (tête) ────┘
//                    cascade φ  ──────────┘  (θ_ref)
//
// MÉCANIQUE RÉELLE (v3) : deux ROUES sur servos à rotation continue
// (FEET_MODE_CONTINUOUS=1, config.h). La sortie du PID est une VITESSE
// de roue, envoyée telle quelle. Une CASCADE DE RECENTRAGE en vitesse
// (boucle externe 10 Hz sur la course φ → consigne de vitesse ; boucle
// interne continue → θ_ref) ramène le robot vers son point de départ ;
// elle ne court-circuite JAMAIS le PID.
// Ancienne mécanique v3.1 (pieds en ARC sur SG90 de position, course
// FINIE) : un soft clamp annule la vitesse avant la butée et un « panic »
// coupe si le pied est trop loin — compilés seulement si
// FOOT_TRAVEL_LIMITED (config.h). Une roue n'a pas de butée.
//
// Cadencé à BALANCE_LOOP_HZ (200 Hz) par le .ino — dans sa propre tâche
// sur le cœur BALANCE_TASK_CORE si BALANCE_SPLIT_CORES ; aucun delay() ici.
// AUCUN Serial dans loop() : USB-CDC peut bloquer (STALL_ANALYSIS.md §6).
// ═══════════════════════════════════════════════════════════════════
#include <Arduino.h>
#include <Preferences.h>

#include "config.h"
#include "interfaces.h"
#include "imu.h"
#include "feet.h"

namespace {

// ═══════════════════ RÉGLAGE PID — commencer ici ═══════════════════
// Unités : erreur en degrés, sortie en « vitesse de pied » (-90..+90,
// convertie en °/s par kOutToFootDegS). Gains de départ pour un châssis
// léger — à affiner sur le robot réel.
//
// Procédure de réglage (robot tenu à la main) — REVIEW_CLAUDE.md M8.
// La sortie est une VITESSE de pied : l'accélération de la base (la seule
// chose qui redresse le pendule) est la DÉRIVÉE de la sortie, soit
// Ki·θ + Kp·θ̇ + Kd·θ̈. Ici Ki est donc la RAIDEUR, Kp l'AMORTISSEMENT et
// Kd une inertie : la recette habituelle d'un PID de position (Ki = Kd = 0,
// monter Kp jusqu'à l'oscillation) ne s'applique PAS — avec Ki = 0 aucune
// oscillation n'est observable, le robot tombe.
//   1. partir de Ki ≈ 400-500 (> g/R ≈ 302 s⁻², condition ci-dessous),
//      Kp ≈ 50, Kd ≈ 0,5. Le Kp = 25 embarqué est en dessous : l'analyse
//      linéaire du modèle du sim (retards 50 + 25 ms) le donne instable,
//      Kp 50-100 franchement amorti ;
//   2. monter Kp pour AMORTIR (trop bas → balancement lent qui s'amplifie,
//      trop haut → tremblement) ;
//   3. Kd en dernier, petit (≲ 2) : il ne fait que lisser ; trop → buzz aigu.
//
// Gains de DÉPART, NON validés par une simulation rejouable (voir
// FIRMWARE_REVIEW.md §1bis) : le simulateur du dépôt modélisait un autre
// robot (autorité 57× trop forte, roulement incomplet, sans cascade). Avec
// le modèle corrigé, ce jeu de gains ne tient aucun scénario — le réglage
// réel au banc web (BalanceBot-Tune) est l'étape obligatoire suivante.
//
// Condition de stabilité : la commande agit en VITESSE de pied, donc le
// terme intégral est ce qui fournit la position de pied compensant la
// gravité. Il faut Ki > g/R ≈ 9.81 / 0.0325 ≈ 302 s⁻² pour que le point
// de contact rattrape le CoM ; en dessous, le robot tombe quelle que
// soit la valeur de Kp. L'ancien Ki = 20 (hérité du design « roues »,
// jamais testé) est 15× trop faible → chute systématique en sim.
// NON-const : réglables à chaud par le banc web (tuner.cpp) via
// Balance::setGains(). Des float 32 bits sur ESP32 : lecture/écriture
// atomiques (un seul mot machine), pas de tearing possible entre la
// boucle d'équilibre et le serveur web — ni volatile ni mutex requis.
float kKp = 25.0f;   // vitesse par degré d'erreur
float kKi = 500.0f;  // vitesse par (degré · seconde) — cf. Ki > g/R
float kKd = 0.5f;    // vitesse par (degré / seconde) — sur le gyro

// Bornes de réglage à chaud (garde-fous du banc web)
constexpr float kKpMax = 100.0f;
constexpr float kKiMax = 2000.0f;
constexpr float kKdMax = 20.0f;

// Consigne d'équilibre : angle auquel le robot tient réellement debout.
// Décaler de quelques dixièmes si le robot dérive toujours du même côté.
constexpr float kSetpointDeg = 0.0f;

// ── Morts-zones ────────────────────────────────────────────────────
// Erreur : AUCUNE (0) — REVIEW_CLAUDE.md M3. L'ancienne bande de 0,25°
// était appliquée AVANT P et I : le robot vivait sur son bord, chaque
// sortie de bande donnait un coup de P qui le ramenait juste dedans, où P
// et I étaient gelés ; l'erreur ne changeait donc jamais de signe,
// l'intégrale ne se déchargeait jamais et cliquetait jusqu'à sa borne →
// pieds en butée en 1-2 s quels que soient les gains (reproduit en sim,
// jeu linéairement stable). Le bruit du pitch fusionné (~0,03-0,1° rms)
// ne justifie pas de bande : le SG90 ne répond pas sous ~1° de toute
// façon. Si une bande redevenait nécessaire, ne l'appliquer QU'AU terme
// P, jamais à l'entrée de l'intégrateur. (Le test « < 0 » est inerte.)
constexpr float kErrDeadbandDeg = 0.0f;
// Sortie : plus de mort-zone ni de relèvement (shapeOutput) — c'était
// une compensation du frottement sec des SG90 en rotation continue. En
// commande de POSITION, ce saut 0→8 se traduirait par un bond du pied
// de plusieurs dixièmes de degré à chaque cycle : nuisible.
constexpr float kOutMax       = 90.0f;

// ── Anti-windup ────────────────────────────────────────────────────
// Le terme intégral est borné à la PLEINE sortie (REVIEW_CLAUDE.md M10) :
// en commande de vitesse, I est le terme de RAIDEUR (cf. procédure de
// réglage) ; l'ancien plafond de 25 (28 % de kOutMax) bridait
// l'accélération cumulée de la base — mesuré en sim (mort-zone 0, retard
// 5 ms, k_out 3, gains embarqués) : Imax 25 → 0/6, Imax 90 → θ0 = 2° tenus.
// Le rebond au redressement (I chargé pendant la chute), lui, est déjà
// évité par l'intégration CONDITIONNELLE de Pid::update (gel quand la
// sortie sature).
constexpr float kIntegralMax = kOutMax;

// ── Sortie PID → vitesse de pied ───────────────────────────────────
// Le domaine du PID (-90..+90) est lu comme des °/s de pied. À 1.0,
// pleine commande = 90 °/s ; l'arc a un rayon de 32.5 mm, soit
// 0.567 mm de déplacement au sol par degré → 51 mm/s au maximum.
// C'est le PREMIER bouton à monter si le robot est trop lent à se
// rattraper : un SG90 tient ~300 °/s à vide, donc jusqu'à ~3.0.
// NON-const depuis REVIEW_CLAUDE.md M11 : slider « Autorité » du banc web
// (Balance::setOutScale, borné kOutToFootMin..Max, persisté NVS « kout »)
// et balayé par le --sweep du sim — où aucun jeu ne tient le moindre
// scénario sous k_out = 2, et où les tapes ne sont atteintes qu'à k_out = 3.
// Feet:: écrête de son côté à kSpeedMaxDegS (400 °/s) : 3 × 90 = 270 °/s
// reste dans la plage.
float kOutToFootDegS = 1.0f;
constexpr float kOutToFootMin = 1.0f;
constexpr float kOutToFootMax = 3.0f;

// ── Butée des pieds (débattement fini du servo de position) ────────
// Le pied ET le corps consomment le même arc : le point de contact se
// trouve à ≈ (φ + θ) du milieu de l'arc. La limite utile dépend donc
// du tangage courant. L'arc couvre ±100°, le servo ±90° :
//   limite = 90° − |θ| − marge, plafonnée par la butée dure de feet.cpp.
// La marge (9°) couvre le retard du servo et l'incertitude de calage
// du palonnier (4 positions à 90° : jusqu'à quelques degrés d'erreur).
constexpr float kFootMarginDeg = 9.0f;
constexpr float kFootHardDeg   = FOOT_HARD_DEG;   // = butée dure de feet.cpp (config.h)
// Le soft clamp s'ouvre progressivement sur les 10 derniers degrés :
// une coupure franche exciterait le pendule.
constexpr float kFootTaperDeg  = 10.0f;

// ── Recentrage en CASCADE (remplace le trim d'angle) ───────────────
// Le trim précédent (±0.4° sur θ_ref) était trop faible : après une tape
// qui laissait le pied à 36°, le robot restait collé près de la butée et
// tombait à la perturbation suivante. On asservit désormais la POSITION
// du pied par une cascade classique :
//
//   externe (10 Hz)  : v_cible = kRecenterKpPhi · (0 − φ)   borné ±VelMax
//   interne (200 Hz) : θ_ref  += kRecenterKv · (v_cible − φ̇)  borné ±RefMax
//   PID 200 Hz       : maintient θ = θ_ref (inchangé)
//
// φ̇ est estimé SANS ENCODEUR : dériver la position intégrée par feet.cpp
// serait bruité, on filtre à la place la VITESSE COMMANDÉE par un 1er
// ordre τ = kFootVelTau — ce qui approxime la réponse du servo, et c'est
// exactement ce qui a été simulé (sim/cascade_recenter.md).
//
// Au centre et à l'arrêt (φ = 0, φ̇ = 0) la contribution est nulle : le
// PID retrouve son comportement normal. NON-const : réglables à chaud.
constexpr unsigned long kRecenterPeriodMs = 100;   // 10 Hz (boucle externe)
float kRecenterKpPhi = 0.8f;    // °/s de v_cible par ° d'erreur de pied
float kRecenterKv    = 3.0f;    // ° de θ_ref par °/s d'erreur de vitesse
constexpr float kRecenterVelMax = 20.0f;  // borne de v_cible (°/s)
constexpr float kRecenterRefMax = 6.0f;   // borne de la contribution θ_ref (°)
constexpr float kRecenterSlew   = 3.0f;   // rampe de v_cible (°/s²)
constexpr float kFootVelTau     = 0.08f;  // filtre de la vitesse commandée (s)
constexpr float kFootPanicDeg   = 35.0f;  // butée imminente → halt()

// Bornes de réglage à chaud des gains de cascade
constexpr float kRecenterKpPhiMax = 5.0f;
constexpr float kRecenterKvMax    = 20.0f;

// ── Pilotage depuis l'UI ───────────────────────────────────────────
// Avancer = incliner la consigne dans le sens de la marche.
// 100 (plein gaz) → 6° d'inclinaison : au-delà le robot décroche.
constexpr float kTiltPerCmd  = 0.06f;   // ° par unité de cmdForward
constexpr float kTurnPerCmd  = 0.30f;   // unités de sortie par unité de cmdTurn
constexpr float kCmdSlewPerS = 200.0f;  // lissage des consignes UI (unités/s)

// ── Sécurité ───────────────────────────────────────────────────────
constexpr float        kFallAngleDeg    = 45.0f;  // au-delà : chute
constexpr float        kRecoverAngleDeg = 10.0f;  // redressé sous cet angle…
constexpr unsigned long kRecoverHoldMs  = 700;    // …et stable ce temps-là
constexpr float        kDtMinS = 0.0005f;         // bornes de dt (protection
constexpr float        kDtMaxS = 0.050f;          //  contre les hoquets)
// Trames IMU consécutives perdues tolérées avant coupure : à 200 Hz,
// 20 trames ≈ 100 ms. En deçà, l'angle précédent tient (micro-coupure
// I2C) ; au-delà, on asservirait sur une mesure figée.
constexpr uint16_t     kImuFailMax = 20;

// ── Surveillance de cadence ─────────────────────────────────────────
// Sous ce seuil, la boucle ne pilote plus correctement les pieds (l'UI,
// le TFT ou le web lui ont volé du temps) : on coupe plutôt que de laisser
// un asservissement faux. La grâce couvre le démarrage (WiFi/TFT).
constexpr float         kMinLoopHz   = 120.0f;
constexpr unsigned long kRateGraceMs = 3000;

// ── Mode démo (équilibre OFF) ──────────────────────────────────────
// Sert à VALIDER LA MÉCANIQUE sans asservissement : les flèches de l'UI
// font rouler les pieds lentement (le robot est tenu à la main ou
// couché). Aucune sécurité d'équilibre n'est active ici, d'où les
// valeurs timides.
constexpr float kDemoSpeedDegS = 20.0f;   // à plein cmdForward
constexpr float kDemoTurnDegS  = 12.0f;   // différentiel, à plein cmdTurn
#if FOOT_TRAVEL_LIMITED
// Butée d'arc du mode démo — n'existe qu'en mode POSITION : une roue n'a
// pas de butée, et valider la mécanique en MANUEL suppose de pouvoir la
// faire tourner librement (cf. demoStep).
constexpr float kDemoLimitDeg  = 15.0f;   // débattement autorisé en démo
#endif

// ═══════════════════════════════════════════════════════════════════

// PID minimal, dérivée prise sur la MESURE (gyro) et non sur l'erreur :
// pas de « derivative kick » quand l'UI change la consigne, et le gyro
// donne la vitesse angulaire sans dériver numériquement un signal bruité.
struct Pid {
  float integral = 0.0f;

  void reset() { integral = 0.0f; }

  float update(float error, float rateDps, float dt) {
    const float p = kKp * error;
    const float d = -kKd * rateDps;

    // Intégration conditionnelle : on n'accumule que si la sortie qui
    // en résulterait reste dans la plage utile (anti-windup).
    const float candidate =
        constrain(integral + kKi * error * dt, -kIntegralMax, kIntegralMax);
    const float rawWithCandidate = p + candidate + d;
    if (fabsf(rawWithCandidate) < kOutMax || (rawWithCandidate * error) < 0.0f) {
      integral = candidate;
    }
    return p + integral + d;
  }
};
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
void loop() {
  // Le .ino appelle loop() en continu (200 Hz). L'asservissement ne
  // s'active que si isEnabled(), mais la MESURE IMU a toujours lieu :
  // le PITCH affiché par l'UI doit vivre même robot posé à l'arrêt.

  // ── Signe de vie pour la surveillance (loop(), autre cœur) ───────
  // Posé au DÉPART du pas : un pas qui bloque (verrou I2C, plantage
  // partiel) est vu figé BALANCE_STALL_MS plus tard.
  g_state.balLastStepMs = (uint32_t)millis();

  // ── Arrêt d'urgence : verrouillé jusqu'au RESET ──────────────────
  // Rien d'autre ne tourne : ni mesure, ni démo. Les roues sont déjà
  // coupées par emergencyStop() (depuis loop()) ; on le refait ici,
  // idempotent, au cas où l'appel d'origine aurait échoué.
  if (g_state.estop) {
    haltAndCut();
    publishFeet();
    return;
  }

  // ── Reprise après une coupure « boucle figée » ───────────────────
  // La surveillance a détaché les roues pendant qu'on ne tournait pas.
  // On repart PROPRE (intégrateurs vidés) avec les roues réarmées : même
  // philosophie que s_rateLow / s_imuLost (REVIEW_CLAUDE.md M19, reprise
  // automatique dès que la cause disparaît). Si le robot est tombé
  // pendant la coupure, le verrou de chute prend le relais ci-dessous.
  if (s_stallCut) {
    s_stallCut = false;
    Feet::rearm();
    halt();
  }

  // ── Fréquence RÉELLE d'appel (debug UI) ─────────────────────────
  // Compte les appels sur une fenêtre glissante de 1 s. Si l'UI ou la
  // tête (mêmes ressources I2C/CPU) ralentissent la loop, on le voit ici.
  {
    static unsigned long s_count = 0;
    static unsigned long s_winMs = millis();
    s_count++;
    const unsigned long nowMs = millis();
    const unsigned long span = nowMs - s_winMs;
    if (span >= 1000) {
      g_state.balanceHz = s_count * 1000.0f / (float)span;
      s_count = 0;
      s_winMs = nowMs;
      // Surveillance : passé la grâce de démarrage, une cadence sous le
      // seuil met l'asservissement en sécurité (il revient tout seul).
      if (nowMs > kRateGraceMs) s_rateLow = (g_state.balanceHz < kMinLoopHz);
    }
  }

  // Cadence insuffisante : on ne pilote plus (voir kMinLoopHz).
  if (s_rateLow) {
    halt();
    publishFeet();
    return;
  }

  bool want = isEnabled();
  // Refus d'ARMER sur batterie faible : sous BAT_LOW_V la cellule est à
  // ~10 % et l'appel de courant des servos fait s'effondrer la tension
  // (brownout → reboot en pleine correction). On annule la demande.
  // Sur le FRONT MONTANT seulement (REVIEW_CLAUDE.md M6) : testée à chaque
  // itération, cette garde désarmait aussi un robot DEBOUT (halt() →
  // chute) sur un seul échantillon ADC en creux. batteryLow est désormais
  // hystérétique et débouncé (battery.cpp), et un robot déjà en équilibre
  // n'est plus coupé : l'écran (« BAT. FAIBLE ») et le visage rouge
  // préviennent, c'est à l'utilisateur de le poser ; le prochain armement
  // sera refusé.
  if (want && !s_enabled && g_state.batteryLow) {
    g_state.cmdEnabled = false;
    want = false;
  }
  if (want && !s_enabled) {          // front montant : on repart propre
    s_pid.reset();
    s_lastMicros = micros();
    s_uprightSince = 0;
    // Armement par g_state.cmdEnabled (l'UI et le banc web n'appellent pas
    // setEnabled) : sans ça, s_recenterLast daterait de la dernière
    // désactivation et le premier pas de la boucle externe verrait un dt
    // de plusieurs secondes — soit toute la rampe franchie d'un bloc.
    s_recenterLast = millis();
    s_recenterVel = 0.0f;
    s_footVelFilt = 0.0f;
  } else if (!want && s_enabled) {   // front descendant : arrêt propre
    halt();
  }
  s_enabled = want;

  if (!s_imuOk) {
    // Pas d'IMU : aucun équilibre possible, mais la mécanique reste
    // pilotable en démo par les flèches de l'UI.
    // halt() sur FRONT seulement (REVIEW_CLAUDE.md M7) : appelé à chaque
    // itération, il réarmait Feet::s_lastMicros (via Feet::stop()) quelques
    // µs avant le driveFootSpeed() de demoStep(), qui voyait dt ≈ 20 µs →
    // borné à 0,5 ms au lieu des 5 ms réels : la démo roulait 10× trop
    // lentement. s_imuOk est figé au boot : le seul front est la première
    // itération (un désarmement passe, lui, par le front descendant traité
    // plus haut, qui appelle halt()).
    static bool s_noImuHalted = false;
    if (!s_noImuHalted) {
      s_noImuHalted = true;
      halt();
    }
    demoStep();
    return;
  }

  // Servos de pieds non attachés : φ resterait à 0 alors que les pieds
  // sont morts — le robot « équilibrerait » dans le vide et tomberait.
  if (!Feet::ready()) {
    halt();
    demoStep();
    return;
  }

  // ── dt réel (le .ino cadence à ~5 ms, mais ne le suppose pas) ────
  const unsigned long now = micros();
  float dt = (now - s_lastMicros) * 1e-6f;   // le calcul non signé gère le rollover
  s_lastMicros = now;
  dt = constrain(dt, kDtMinS, kDtMaxS);

  // ── Mesure ───────────────────────────────────────────────────────
  // Une trame perdue (bus I2C secoué) : l'angle précédent tient. Au-delà
  // de kImuFailMax consécutives, on asservirait sur une mesure FIGÉE — on
  // coupe et on attend le retour du capteur (s_imuLost se relève seul dès
  // qu'une trame repasse). Un capteur qui ACK mais renvoie des registres
  // figés compte aussi comme « trame perdue » (imu.cpp, kFrozenMax —
  // REVIEW_CLAUDE.md M9).
  static uint16_t s_imuFailStreak = 0;
  if (Imu::update(dt)) {
    s_imuFailStreak = 0;
    s_imuLost = false;
  } else if (++s_imuFailStreak >= kImuFailMax) {
    s_imuLost = true;
    halt();
    publishFeet();
    return;
  }
  const float pitch = Imu::pitchDeg();
  const float rate  = Imu::pitchRateDps();
  g_state.pitchDeg  = pitch;
  s_lastRateDps     = rate;          // exposé au banc web (télémétrie seule)

  // À l'arrêt (équilibre OFF) : on a mesuré pour l'affichage, on ne
  // pilote pas l'équilibre — seul le mode démo peut bouger les pieds.
  if (!s_enabled) {
    demoStep();
    return;
  }

  // ── Sécurité : chute ─────────────────────────────────────────────
  if (fabsf(pitch) > kFallAngleDeg) {
    s_fallen = true;
    s_uprightSince = 0;
    haltAndCut();                    // roues COUPÉES : rien ne tourne au sol
    publishFeet();
    return;
  }
  if (s_fallen) {
    // Redressement manuel : il faut être vertical ET stable un moment
    // avant de relancer l'asservissement.
    if (fabsf(pitch) < kRecoverAngleDeg) {
      const unsigned long ms = millis();
      if (s_uprightSince == 0) s_uprightSince = ms;
      if (ms - s_uprightSince >= kRecoverHoldMs) {
        s_fallen = false;
        s_pid.reset();
        // Le robot est tenu droit à la main : c'est le SEUL moment où
        // réarmer les roues (PWM ré-attaché, à l'arrêt) puis ramener la
        // course au neutre est sans danger — et c'est indispensable,
        // sinon on ré-arme avec des pieds déjà en butée (mode arc).
        Feet::rearm();
        Feet::recenterNow();
        s_recenterLast = millis();
      }
    } else {
      s_uprightSince = 0;
    }
    if (s_fallen) { haltAndCut(); publishFeet(); return; }
  }

  // ── Consignes UI (lissées : un cran brutal fait décrocher) ───────
  int cmdFwd  = constrain(g_state.cmdForward, -100, 100);
  int cmdTurn = constrain(g_state.cmdTurn, -100, 100);
  // Obstacle détecté par le module C : on interdit la marche avant,
  // la marche arrière et l'équilibre restent actifs.
  if (g_state.obstacleWarn && cmdFwd > 0) cmdFwd = 0;
  // ── Évitement (head.cpp → BotState) — ÉQUILIBREUR D'ABORD ─────────
  // L'évitement ne touche QUE les consignes de déplacement, ici, AVANT le
  // lissage : tout ce qui suit (cascade, PID, différentiel, roues) est
  // inchangé. avoidFwdMax plafonne la marche avant (100 = libre, 40 =
  // ralenti, 0 = stop, négatif = recul doux imposé) ; avoidTurn impose un
  // pivot vers le côté libre seulement si l'utilisateur ne tourne pas
  // lui-même. Un recul plus franc demandé par l'UI garde la priorité
  // (min). Jamais de coupure : une roue coupée, c'est un robot par terre.
  if (cmdFwd > g_state.avoidFwdMax) cmdFwd = g_state.avoidFwdMax;
  if (cmdTurn == 0 && g_state.avoidTurn != 0) cmdTurn = constrain(g_state.avoidTurn, -100, 100);

  const float maxStep = kCmdSlewPerS * dt;
  s_fwdSmooth  = slew(s_fwdSmooth,  (float)cmdFwd,  maxStep);
  s_turnSmooth = slew(s_turnSmooth, (float)cmdTurn, maxStep);
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

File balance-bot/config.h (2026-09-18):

#pragma once
// ═══════════════════════════════════════════════════════════════════
// BalanceBot — configuration centralisée (pins + constantes)
// Carte : LilyGo T-Display-S3-Touch (ESP32-S3R8, 16MB, 8MB OPI PSRAM)
// Référence pinout : repo officiel Xinyuan-LilyGO/T-Display-S3
// Ce fichier est la SOURCE UNIQUE des affectations. Les modules le
// lisent ; aucun agent ne doit le modifier sans validation Hermes.
// ═══════════════════════════════════════════════════════════════════

// ── Écran / Touch (occupés — ne pas réutiliser) ────────────────────
#define PIN_LCD_BL      38
#define PIN_LCD_D0      39
#define PIN_LCD_D1      40
#define PIN_LCD_D2      41
#define PIN_LCD_D3      42
#define PIN_LCD_D4      45
#define PIN_LCD_D5      46
#define PIN_LCD_D6      47
#define PIN_LCD_D7      48
#define PIN_POWER_ON    15     // DOIT être HIGH avant usage écran
#define PIN_LCD_RES     5
#define PIN_LCD_CS      6
#define PIN_LCD_DC      7
#define PIN_LCD_WR      8
#define PIN_LCD_RD      9
#define PIN_BUTTON_1    0      // BOOT
#define PIN_BUTTON_2    14
#define PIN_BAT_VOLT    4      // ADC batterie (USB débranché)
#define PIN_TOUCH_INT   16
#define PIN_TOUCH_RES   21

// ── I2C (IMU MPU6050 — bus Qwiic/STEMMA) ───────────────────────────
#define PIN_IIC_SCL     17
#define PIN_IIC_SDA     18

// ── Servos (GPIO libres) ───────────────────────────────────────────
// Mécanique v3 RÉELLE (chassis/NOTES_v3.md, docs/photos/robot-reel.jpg) :
// deux ROUES entraînées par des servos 9 g à ROTATION CONTINUE 360°
// (taille SG90/FS90R). Les GPIO 1 et 2 pilotent ces deux roues. Le nom
// « FOOT » est conservé dans le code (feet.cpp) : l'API commande une
// VITESSE de roue et intègre la course φ, ce qui vaut pour les deux
// matériels — voir FEET_MODE_CONTINUOUS ci-dessous.
#define SERVO_FOOT_L    1      // roue gauche — servo continu (cf. FEET_MODE_CONTINUOUS)
#define SERVO_FOOT_R    2      // roue droite — servo continu (cf. FEET_MODE_CONTINUOUS)
#define SERVO_HEAD_PAN  3      // tête : rotation horizontale (SG90 standard)
#define SERVO_HEAD_TILT 10     // tête : inclinaison (SG90 standard)

// ── TYPE des servos de ROUES — sélecteur de mode (compile-time) ─────
// Deux matériels possibles sur les mêmes broches, même boîtier 23×12.2×29 :
//   0 = SG90 STANDARD 180° (ancienne mécanique v3.1 « pieds en arc ») : le
//       servo ne connaît que la POSITION. feet.cpp intègre la vitesse du
//       PID (°/s) en position (°) et écrit l'angle. Débattement FINI.
//   1 = servo à ROTATION CONTINUE 360° (ROBOT RÉEL) : le servo ne connaît
//       que la VITESSE (1500 µs = arrêt, ±500 µs = pleine vitesse). La
//       sortie du PID part DIRECTEMENT au servo, sans intégration position.
//
// POURQUOI 1 EST LE BON MODE POUR CE MATÉRIEL : un servo continu n'a pas
// d'asservissement de position interne — lui envoyer un « angle » n'a
// aucun sens, l'impulsion est lue comme une vitesse. Avec le mode 0 sur
// des servos continus, l'écriture d'une position croissante (ex. 1600 µs)
// ferait TOURNER la roue en continu au lieu de la déplacer de quelques
// degrés : le robot partirait à pleine vitesse au premier écart de pitch.
// C'est aussi ce que simulent sim/balancebot_sim.py et le simulateur web
// (MODE = "roue") — la règle d'or (scripts/verifier-regle-or.py) exige que
// firmware et simulateurs disent la même chose.
//
// Le mode continu conserve malgré tout l'intégration interne de φ : le
// soft clamp de balance.cpp (Feet::angleAvg()) et la butée dure lisent
// cette course « conventionnelle ». Voir feet.cpp pour la calibration
// µs/(°/s) et le trim du neutre.
//
// Revenir au mode POSITION : compiler avec -DFEET_MODE_CONTINUOUS=0 ou
// changer la valeur ci-dessous — un seul #define, rien d'autre à toucher.
#ifndef FEET_MODE_CONTINUOUS
#define FEET_MODE_CONTINUOUS 1
#endif
// COURSE FINIE (arc) ou LIBRE (roue). Une roue tourne sans fin : la butée
// dure ±FOOT_HARD_DEG de feet.cpp, le soft clamp de butée et le « panic »
// à kFootPanicDeg de balance.cpp n'ont plus d'objet — et le simulateur en
// MODE = "roue" ne les modélise pas (règle d'or). Ils restent VITAUX en
// mode position (arc) : dérivé du mode, surchargeable par -D si un jour
// un servo continu entraînait un arc à course finie.
#ifndef FOOT_TRAVEL_LIMITED
#define FOOT_TRAVEL_LIMITED (!FEET_MODE_CONTINUOUS)
#endif

// ── Ultrason HC-SR04 ───────────────────────────────────────────────
#define PIN_US_TRIG     11
#define PIN_US_ECHO     12
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

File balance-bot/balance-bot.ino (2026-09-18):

// ═══════════════════════════════════════════════════════════════════
// BalanceBot — sketch principal (assemblage)
// T-Display-S3-Touch (ESP32-S3) · 2 roues sur servos continus + tête
// pan/tilt (SG90) · MPU6050 (I2C) · HC-SR04 · châssis imprimé ₿
//
// RÉPARTITION SUR LES DEUX CŒURS (BALANCE_SPLIT_CORES = 1, config.h) :
//   cœur 0, tâche « balance », priorité BALANCE_TASK_PRIO :
//       capteur d'assiette → correcteur → roues, à BALANCE_LOOP_HZ,
//       cadencée par vTaskDelayUntil (période exacte, sans dérive) ;
//   cœur 1, loop() Arduino : écran (60 Hz), tête + ultrason (50 Hz —
//       le pulseIn() bloquant y vit désormais sans toucher l'équilibre),
//       batterie (1 Hz), boutons, surveillance de la boucle d'équilibre.
//   Le banc web (tuner.cpp) garde sa propre tâche, déplacée sur le cœur 1.
// Avec BALANCE_SPLIT_CORES = 0 : tout dans loop(), comme avant (repli).
// Dans les deux cas Balance::loop() est appelée à la MÊME cadence, avec
// la MÊME loi de commande : seul l'appelant change.
//
// PARTAGE DE DONNÉES : uniquement via g_state (BotState, interfaces.h),
// « un mot machine, un seul écrivain » — voir le commentaire du struct.
// ═══════════════════════════════════════════════════════════════════
#include <Arduino.h>

#include "config.h"
#include "interfaces.h"
#include "tuner.h"
#include "ui.h"          // Ui::showTip() (appui court KEY)

// État global unique — défini ICI, déclaré extern dans interfaces.h
BotState g_state;

// ── Un pas d'équilibre, avec sa mesure de durée ─────────────────────
// Partagé par les deux modes de compilation : la tâche (cœur 0) ou la
// phase de loop() (mono-cœur) appellent exactement ceci.
static inline void balanceStep() {
  const unsigned long t0 = micros();
  Balance::loop();
  const unsigned long dt = (micros() - t0) / 1000UL;
  if (dt > g_state.dbgBalMs)    g_state.dbgBalMs    = (uint8_t)min(dt, 255UL);
  if (dt > g_state.dbgBalMaxMs) g_state.dbgBalMaxMs = (uint16_t)min(dt, 65535UL);
}

#if BALANCE_SPLIT_CORES
// ── Tâche d'équilibre (cœur BALANCE_TASK_CORE) ──────────────────────
// vTaskDelayUntil : réveil à t0 + n·période, sans accumuler de retard.
// FreeRTOS tourne à 1000 Hz (CONFIG_FREERTOS_HZ) → 200 Hz = 5 ticks
// exacts. La tâche cède le cœur entre deux pas : l'IDLE0 tourne (le
// watchdog de tâche surveille l'IDLE du cœur 0), le WiFi (priorité 23)
// aussi. Aucun Serial ici : USB-CDC peut bloquer (STALL_ANALYSIS.md §6).
static TaskHandle_t s_balanceTask = nullptr;

static void balanceTask(void*) {
  TickType_t last = xTaskGetTickCount();
  const TickType_t period = pdMS_TO_TICKS(1000 / BALANCE_LOOP_HZ);
  for (;;) {
    vTaskDelayUntil(&last, period);
    balanceStep();
  }
}
#endif

void setup() {
  Serial.begin(115200);
  delay(200);
  Serial.println("\n═══ BalanceBot boot ═══");

  // Power ON les périphériques (GPIO15 HIGH = obligatoire sur T-Display S3)
  pinMode(PIN_POWER_ON, OUTPUT);
  digitalWrite(PIN_POWER_ON, HIGH);

  // Boutons : BOOT (GPIO 0) = ARRÊT D'URGENCE (appui > ESTOP_HOLD_MS),
  // KEY (GPIO 14) = appui LONG : ouvrir/fermer le banc web ; appui COURT :
  // écran pourboire (QR Lightning — ROADMAP 4.2 étape 1).
  pinMode(PIN_ESTOP, INPUT_PULLUP);
  pinMode(PIN_TUNER_TOGGLE, INPUT_PULLUP);

  Battery::begin();

  if (Ui::begin())      Serial.println("UI        : OK");
  else                  Serial.println("UI        : ÉCHEC");

  if (Balance::begin()) Serial.println("ÉQUILIBRE : OK (IMU présent)");
  else                  Serial.println("ÉQUILIBRE : IMU absent — mode démo UI seulement");

  if (Head::begin())    Serial.println("TÊTE+US   : OK");
  else                  Serial.println("TÊTE+US   : ÉCHEC");

  // Banc de réglage web (AP « BalanceBot-Tune » → http://192.168.4.1).
  // Un échec n'empêche pas le boot : Tuner::loop() devient un no-op et
  // le robot se comporte exactement comme sans ce module.
  Tuner::begin();

#if BALANCE_SPLIT_CORES
  // Lancée en DERNIER : tous les begin() (I2C, servos, NVS) sont faits,
  // la tâche ne partage plus rien d'autre que g_state avec ce cœur.
  const BaseType_t ok = xTaskCreatePinnedToCore(
      balanceTask, "balance", BALANCE_TASK_STACK, nullptr,
      BALANCE_TASK_PRIO, &s_balanceTask, BALANCE_TASK_CORE);
  if (ok == pdPASS) Serial.printf("ÉQUILIBRE : tâche sur le cœur %d, priorité %d, %d Hz\n",
                                  BALANCE_TASK_CORE, (int)BALANCE_TASK_PRIO, BALANCE_LOOP_HZ);
  else              Serial.println("ÉQUILIBRE : ÉCHEC de création de la tâche — ROUES INERTES");
#else
  Serial.println("ÉQUILIBRE : mono-cœur (BALANCE_SPLIT_CORES = 0), dans loop()");
#endif

  Serial.println("═══ BalanceBot prêt ═══");
}

void loop() {
  const unsigned long nowMs = millis();
  const unsigned long loopT0 = micros();

  // ── Diagnostic de cadence (enquête 09/09) ───────────────────────
  // L'écart entre deux départs de loop() dit si la boucle a été retardée ;
  // la durée du corps (loopT0) dit si le retard vient de DEDANS. Les deux
  // ensemble séparent « phase lente » de « blocage externe » (WiFi, cache
  // flash, interruptions). s_lastPhase = dernière phase exécutée.
  static uint8_t       s_lastPhase = 5;
  static unsigned long tPrevLoop   = 0;
  static uint8_t       s_prevLoopMs = 0;
  const unsigned long gap = nowMs - tPrevLoop;
  tPrevLoop = nowMs;
  if (gap > g_state.dbgGapMs) {
    g_state.dbgGapMs   = (uint16_t)min(gap, 65535UL);
    g_state.dbgGapPhase = s_lastPhase;
  }
  if (gap > g_state.dbgWorstMs) g_state.dbgWorstMs = (uint16_t)min(gap, 65535UL);
  if (gap > 100) {                     // gros décrochage : on garde sa signature
    g_state.dbgBigGaps++;
    g_state.dbgLastGapMs     = (uint16_t)min(gap, 65535UL);
    g_state.dbgLastGapPhase  = s_lastPhase;
    g_state.dbgLastGapLoopMs = s_prevLoopMs;
  }
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

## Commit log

2026-09-04 BalanceBot : firmware ESP32-S3 self-balancing (équilibre PID + UI tactile + tête ultrason)
2026-09-06 UI v5 paysage 320×170 validée (170×320 réel + CGRAM_OFFSET + init ST7789V) ; châssis 3D complet (5 STL vérifiés) ; build.sh avec defines
    [body.stl, head_pan.stl, head_tilt.stl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]
2026-09-06 Châssis v2 (body 2 parties + foot_arc + capteur corrigé) ; firmware : cadences 60/50 Hz, fréquence réelle affichée, timeout I2C 2ms, ultrason adaptatif ; Lot 1 partiel (isFallen, toggle armé, latch, 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
    [body.stl, body_a.stl, body_b.stl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]
2026-09-07 Lot 1 complet : bugs critiques corrigés (moyenne US ×5, pan/tilt float 30°/s, Head::begin réel, batterie -1/USB + seuil 3.5V, code mort supprimé, hygiène firmware/ + calibration/)
    [balance-bot.ino, battery.cpp, config.h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]
2026-09-07 Lot 2 : étage actionneur POSITION (feet.cpp) — pieds en arc SG90 standard, intégration float dt réel, butée dure ±45° + soft clamp dynamique 90°-|θ|-9°, recentrage 2 Hz θ_ref (halt >40°), recenterNow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
2026-09-07 Simulation 1D du pendule inversé (pieds en arc) : prouve Ki>g/R≈300 requis (Ki=20 actuel insuffisant), valide Kp25/Ki500/Kd0.5, montre la fragilité du recentrage par trim
2026-09-07 sim : friction de roulement retirée (artefact de modélisation déstabilisant — le modèle sans friction = pire cas conservateur)
2026-09-07 TEST_PROTOCOL.md : protocole de premier essai debout (neutre → démo → signe câblage → tenu → lâcher) + tableau de réglages rapides + limites connues
2026-09-07 BACKLOG : Lots 2/2b faits, protocole prêt — prochaines étapes = test réel
2026-09-07 Lot 5 : banc de réglage web à chaud (tuner.cpp — AP BalanceBot-Tune, sliders Kp/Ki/Kd en direct, télémétrie pitch/rate/pieds/Hz, bouton équilibre, voyant WEB à l'écran) ; gains kKp/kKi/kKd → variable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
    [balance-bot.ino, balance.cpp, interfaces.h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]
2026-09-07 BACKLOG : Lot 5 validé runtime (test HTTP réel par Hermes sur l'AP de la carte)
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2026-09-07 Sensibilité sim : gains v1 tiennent h 50-100 mm / τ≤100 ms ; robot complet tête+mât → Kp40 Ki600 Kd1.5 (via tuner)
2026-09-07 Sim : mobilité limitée à ~2,5 cm documentée (balancier statique — la marche par inclinaison tape la butée ±45° sans boucle de vitesse) ; protocole à jour
2026-09-07 sim : cascade de recentrage en vitesse validée (KP_PHI=0.8 KV=3.0 — φ revient de 36° à 1° après tape) ; limite géométrique de la marche documentée
2026-09-07 Lot 2c : recentrage en cascade (balance.cpp) — boucle externe 10 Hz KP_PHI·(0−φ) → v_cible rampe 3°/s², estimateur φ̇ sans encodeur (filtre τ80ms sur commande post-clamp), boucle interne KV·err_v ±6°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
2026-09-07 Lot 2d : sliders cascade dans le tuner (kpphi/kv — testé runtime : state + POST OK, hz 198)
2026-09-07 Analyse approfondie post-revue : le modèle sim avait 3 défauts (unité rad/° 57×, roulement incomplet ẍ=R·(θ̈+φ̈), servo sans borne d'accélération) ; gains 'validés' non fiables — le contrôle vitesse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
    [balance.cpp]
2026-09-07 foot_tire.stl : pneu TPU antidérapant (manchon U, Ø68.2, interférence 0.2mm, 195°, watertight vérifié) + gen_tire.py paramétré
    [balancebot_chassis_v2.gcode.3mf, body_a.stl, body_b.stl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]
2026-09-07 Lot 3a : support servos 360° CONTINU (feet.cpp) — #define FEET_MODE_CONTINUOUS, vitesse directe 1500±v µs, garde butée ±45° par coupure explicite, stop/recenter adaptés ; balance.cpp intact ; compile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
2026-09-08 ₿ BalanceBot v3 : châssis symbole Bitcoin (gen paramétrique Blender)
    Corps = glyphe ₿ 90x170+barres, coques 2 moitiés joint y=0, contre-poinçons
    avec fenêtre écran paysage + yeux HC-SR04. Roues-pièces ₿ Ø70 gravées avec
    moyeu Ø24x13 + tubes-paliers Ø26.5/24.5, bandes TPU. Servos 9g continus tête
    en bas sur cloisons, MPU6050 au niveau de l'axe (z=36.5), plots goujons Ø5.8 +
    vis M3, baies carte T-Display / HC-SR04 / switch / USB-C.
    Stabilité booléenne : alésages limités aux tubes, avant-trous M3 avant coupe.
    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
    [b_back.stl, b_front.stl, coin_tire.stl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]
2026-09-08 v3.1 : grille élargie (₿ 118×165, ratio 1.40) + plot servo débloqué
    Grille (review Opus) : GW 118, GH 165, Z0 26, SPINE 20, STROKE 19,
    HIGH_SCALE 0.90, BAR 11×22, LEG 14, DEPTH 46. Roues Ø80 (AXLE_Z 42),
    bande TPU adaptée. Plot vis LOW déplacé hors de la fenêtre du servo
    droit (cavité basse x70,z33) — robot assemblable. Sondages trimesh :
    spine/plots/panses OK, fenêtres servo vides.
    [b_back.stl, b_front.stl, coin_tire.stl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]
2026-09-08 cleanup: purge châssis v2 + brouillons v3 ; coques v3.1 print-ready (peau 0.6 au joint, barres ancrées 4 mm, COUNTER 1.6, meshes fermés)
    [b_back.stl, b_front.stl, balancebot_chassis_v2.gcode.3mf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]
2026-09-09 chassis v3.1 : correction alesages de palier (bouchon) + purge des voiles d'epaisseur nulle + plaques de slicing regenerees
    - bearR/bearL depassent le bout des tubes de 2 mm : le fond coplanaire laissait un
    bouchon/voile dans le tube GAUCHE (moyeu 13 mm impossible a enfoncer)
    - purger_dechets() : suppression des composantes a epaisseur nulle (connectivite par
    aretes) -> b_back 1 composante watertight, profondeur reelle 29 (34,9 avant = voile flottant)
    - chassis/make_plates.py : regeneration des plaques export/v31 (transformations verifiees,
    100 % des sommets alignes) ; les plaques precedentes etaient perimees (version fermee)
    - NOTES_v3.md : cotes mesurees, coques creuses, reglages de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
    [b_back.stl, b_front.stl, plate1_b_front.stl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]
2026-09-09 chassis v3.1 : bouchage des micro-trous (<30 mm) + STL/plaques finaux verifies 25/25
    - boucher_micropores() : comble les boucles de bord libres de petit perimetre (le micro-trou
    0,6 mm pres de l'oeil HC-SR04 etait la derniere arete libre du front)
    - 4 STL : 0 arete libre, 0 non-manifold, watertight ; cotes et volumes inchanges
    - plaques export/v31 regenerees depuis ces STL
    [b_back.stl, b_front.stl, plate1_b_front.stl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]
2026-09-09 chassis/review : rapport d'audit + outils de verification (autonomes, sans /tmp)
    - RAPPORT_IMPRESSION_v31.md : revue complete mesuree + renvoi vers les corrections appliquees
    - verif_ultime.py : controle 25 points (0 arete libre, 0 non-manifold, cotes, fonctions) -> 25/25
    - audit.py / faces.py / test_ouverture.py / diag_roue.py / find_transform.py : outils de sondage
    - mesures_baseline.json : mesures de reference avant corrections
    - README.md : mode d'emploi de la chaine (gen -> make_plates -> verif)
    [audit.py, diag_roue.py, faces.py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]
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2026-09-09 Review firmware : 13 fautes corrigées + simulateur rendu fidèle au firmware
    Firmware (compile vérifiée, 78% flash / 15% RAM, 0 warning) :
    - source unique FOOT_HARD_DEG (config.h) au lieu de deux littéraux 45
    - garde-fou IMU muet (>100 ms sans trame -> halt, reprise auto)
    - refus d'armer si servos de pieds non attachés ; purge des consignes UI à l'armement
    - ADC batterie calibré (analogReadMilliVolts) au lieu d'un scaling linéaire
    - tuner : argument non numérique -> gain inchangé (plus de gain mis à 0 par un POST tronqué)
    - IMU : les deux adresses testées complètement (présence ET WHO_AM_I)
    - ultrason : timeout aligné sur la portée utile (-3 ms de blocage) ; servos tête éc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
    [balance-bot.ino, balance.cpp, battery.cpp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]
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2026-09-09 Correctifs revues Claude : miroir X tactile (armement accidentel), visage AUTO durci
    Tactile (TOUCH_REVIEW.md) :
    - miroir X explicite dans readTouch() : sans lui, appuyer sur AVANT/GAUCHE
    tombait dans la zone du bouton EQUILIBRE et ARMAIT le robot
    - bornage 0..319 / 0..169 avant miroir, multi-touch limite au point 0
    - diagnostic /api/touch (brut + ecran + n de tap), commentaires rectifies
    Visage AUTO (FACE_REVIEW.md, 3 bloquants + 4 importants) :
    - faceEnter()/faceLeave() : effacement du pourtour en 4 bandes, caches du
    visage reinitialises, consignes MANUEL purgees
    - verrou tactile g_touchLatch : le tap sur STOP ne re-arme plus le robot,
    l'armement au doigt n'ouvre plus l'ecran STOP
    -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
    [tuner.cpp, ui.cpp]
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2026-09-09 Cadence 200 Hz : cause racine trouvee et corrigee (auto-sleep du CST816)
    Enquete instrumentee (nouvelles mesures exposees par /api/state) :
    - gap/gph/loop/bal/ui/head/bat + max cumulatifs + touchmax/drawmax
    - signature des gros ecarts (>100 ms) conservee
    Diagnostic :
    - le corps de loop() reste court (balance 1 ms, head 9 ms, dessin 0 ms)
    - mais Ui::loop() atteint 1002 ms, et TOUT le temps est dans
    g_touch->read() (touchmax=1001 ms)
    - A/B a chaud (/api/touch?skip=1) : 21 chutes en 60 s avec la lecture
    tactile, 0 sans -> causalite prouvee
    Cause racine : le CST816 se met en veille (auto-sleep) ; une lecture
    pendant son cycle de reveil tient le bus I2C ~1000 ms (le driver attend,
    notre Wir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
    [balance-bot.ino, interfaces.h, tuner.cpp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]
2026-09-09 fillPoly : ignore les lignes a nombre impair d'intersections + STALL_ANALYSIS.md (enquete cadence) + brief de revue finale
    [ui.cpp]
2026-09-09 FIRMWARE_REVIEW : pointeur vers STALL_ANALYSIS.md et bilan de la nuit
2026-09-10 Correctifs FINAL_REVIEW (revue Claude de la nuit) : 3 moyens + 5 faibles
    Moyens :
    1. tuner.cpp : buf 384→512 o + test du retour snprintf. 19 champs de cadence
    ajoutes cette nuit = ~354 o reels (331 mesures) et jusqu'a ~410 o compteurs
    satures : l'ancien tampon laissait 30 o de marge et un JSON tronque aurait
    bloque la page du banc sur « hors ligne… ».
    2. balance-bot.ino : s_lastPhase = 1 dans le bloc UI (jamais affecte !) — un
    blocage de Ui::loop() etait etiquete « phase 0 = balance ». Et s_prevLoopMs
    = duree de l'iteration courante (et non le max de la seconde).
    3. ui.cpp : retour apres chaque bande d'effacement a l'entree en AUTO — la 1re
    image cumulait bande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
    [balance-bot.ino, balance.cpp, interfaces.h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]
2026-09-10 Châssis : ouverture écran 40.6x22.6 -> 56x26 (demande user)
    La dalle T-Display-S3 Touch + son encadrement ne passaient pas : 26 mm = largeur
    reelle du PCB (62x26), 56 mm laisse une levre de 3 mm de chaque cote sur 62.
    La poche PCB derriere (62.6x26.6) reste plus large, l'epaulement d'appui est
    conserve. Controle projet verif_ultime.py : 25/25 (fenetre debouchante, pieces
    watertight, cotes inchangees).
    [b_back.stl, b_front.stl]
2026-09-10 Plaques de slicing export/v31 regenerees apres l'ouverture 56x26
    make_plates.py relance : plate1_b_front passe a 10084 triangles (= le nouveau
    b_front ; l'ancien en avait 10086). Coques arriere, roues et pneus inchanges
    (geometrie identique : memes bbox, volume, sommets et faces).
    [plate1_b_front.stl, plate2_b_back.stl]
2026-09-10 Vue eclatee + vue interne du chassis (rendus Blender) + doc a jour
    chassis/assets/vue_eclatee.py : reconstruit l'ensemble en 3D a partir des STL
    reels + des cotes du projet (servo 9 g 22.8x12.2x22.5, carte 62x26, axe roue
    z=41.5, voie 108, HC-SR04 entraxe 26, MPU sur piedestal z=36.5), eclate par
    directions de montage, etiquettes face camera. Deux rendus style plan technique
    (fond clair, aretes marquees, camera orthographique) :
    chassis/render/eclate_iso.png (vue eclatee, 8 reperes)
    chassis/render/interne_avant.png (interne, coque avant masquee)
    NOTES_v3.md : etape 6 corrigee (fenetre 56x26, lcz 72).
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2026-09-10 Châssis : baies servo corrigées — le SG90 rentre (intersection 0 mm3)
    Constat utilisateur : le servo bute sur un taquet et un plot de fixation tombe
    en plein milieu de la baie ; ~1 mm de jeu manquant.
    Mesure par intersection booléenne (chassis/review/servo_fit.py, relancé et
    vérifié) : 1497,6 mm3 AVANT → 0,0 mm3 APRÈS. Zones trouvées :
    - goujon pins[0] Ø9 à (10 ; 38) en plein milieu de la baie : 707,8 mm3 ;
    - cloison 'bulk' posée PILE dans le volume des oreilles (erreur de signe sur
    x_bulk_out, recouvrement 2,5/2,5) : 708 mm3 des deux côtés ;
    - paroi courbe résiduelle côté panse : 81,8 mm3.
    Bonus : la boîte bulk n'était pas clippée à la cavité → bosse hors peau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
    [Servo-SG90.stl, Servo-sg90.step, b_back.stl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]
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2026-09-10 Fix hiérarchie : le corps était monté de travers (décalé de 64,5 mm)
    Le refactor en empty 'robot' / 'pivot' appliquait une DOUBLE compensation : le
    pivot était posé à l'origine LOCALE du robot (donc déjà sur l'axe des roues) et
    recevait en plus l'inverse de parent PIVOT⁻¹. Résultat : le pivot se retrouvait à
    (0,0,0) et tout le corps partait avec lui, alors que les roues, enfants de
    'robot', restaient à leur place.
    Mesuré : la dalle à (-6,07 ; 19,6 ; 30) au lieu de (58,5 ; 19,6 ; 72).
    Conséquence : le robot des rendus précédents était éclaté en silence, le corps
    décalé de 64,5 mm en x et 42 mm en z par rapport aux roues — invisible à l'œil
    sur une vidéo floue,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
2026-09-10 Cinématique v4 : démonstration finalisée, plan final revalidé
    Bilan de la mise au point du plan large :
    - à 1,9 m puis 1,05 m, le robot sortait du cadre par le bas et les matériaux
    métalliques s'éteignaient (chute en 1/d2 non compensée). Le studio est calibre
    pour un cadrage serre/moyen : l'eclairage et le sol ne tiennent pas au-dela.
    - fin ramenee a 860 mm, dans la plage 680-830 mm dont le rendu est valide, avec
    compensation exacte de la loi en carre inverse (x1,05 a 820, x1,16 a 860).
    - piege corrige : un 'continue' silencieux quand une lampe est introuvable
    masquait tout le correctif d'eclairage. Desormais une lampe absente fait
    echouer le script au lieu de passer inape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
2026-09-10 Cinématique v6 : visage expressif, décor de chambre, rig d'éclairage, rythme vif
    Rendu complet livré : 780 images, 1280x720, 16 échantillons + débruitage,
    26 s (4,2 Mo, H.264). Contrôle par planche d'images : robot entier et bien
    éclairé sur tous les plans d'ensemble, décor visible (parquet, mur dégradé),
    et l'écran montre bien le VISAGE — yeux ouverts au réveil, plissés au sprint,
    arcs rieurs à la fin — jamais l'interface tactile.
    Corrections de cette passe :
    - caméra recalculée sur le FOV VERTICAL réel (9,27°) : sous 700 mm le robot
    était coupé, les plans d'action sont à 880-900 mm ;
    - plan final = push-in sur le VISAGE (150 mm) au lieu d'un plan large
    impos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
2026-09-16 Revue Kimi K3 + corrections : variable morte, commentaire 'validés' faux, refs périmées, bug du simulateur (tape ×7)
    [balance.cpp, feet.cpp, ui.cpp]
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2026-09-17 17 corrections de la revue Claude : mort-zone 0, signe cascade aligné sim/firmware, soft clamp sim, batterie front montant+débounce, plafond intégral, autorité exposée, IMU figée, calibrate, cosmétiq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
    [balance-bot.ino, balance.cpp, battery.cpp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]
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2026-09-17 Simulateur : corrige les points de la contre-verification capteurs
    - distance capteur calculee analytiquement depuis la pose physique
    (sim.state), plus depuis le maillage : les animations ne la touchent
    plus (mesure Playwright : 13,215 cm fixe, delta 0,000 cm sur les 4
    animations, contre 1,34 cm d'oscillation avant)
    - un seul module HC-SR04 en 3D (comme le robot reel et config.h),
    centre dans le lobe haut du B, au-dessus de l'ecran
    - ultrason.js reproduit le vrai budget pulseIn (attente du front ECHO
    ~480 us incluse) : seuil d'echo a 155 cm comme le robot reel, pas 164
    - auto-test : 4 controles en plus (vitesses pan/tilt mesurees, bornes
    tilt en balayage, angle vu hors centre) +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
2026-09-18 CI : corrige deux faux pas qui l'auraient rendue rouge des le premier passage — le controle de ressource externe criait au loup sur les fetch( internes de Three.js (on teste desormais les sources, pa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
2026-09-18 Firmware : corrige les 3 points non bloquants de la revue deux coeurs
    - demoStep() : la butee d'arc +/-15 deg n'est compilee qu'en mode POSITION
    (FOOT_TRAVEL_LIMITED) — en mode roues la validation manuelle peut faire
    tourner les roues librement, comme le simulateur
    - tuner : la course toggle() <-> handleClient() est fermee par deport des
    transitions radio dans serverTask (drapeau s_wantUp) — WiFi.mode() ne
    croise plus jamais une requete en cours, sans mutex ni attente
    - watchdog : couvre la tache d'equilibre jamais creee (balLastStepMs a 0
    -> roues detachees) ; le cas loop() durablement lente est documente au
    bon endroit (incouvrable sans troisieme base de temps)
    Gains, PID,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
    [balance.cpp, tuner.cpp]
2026-09-18 Simulateur : miroir du firmware 10044c0 — couche déplacement + évitement d'obstacle, tête qui balaie en équilibre (ROADMAP 3.1)
    Le firmware réagit désormais à l'obstacle (ralenti < US_SLOW_CM, recul doux + pivot
    du côté libre < US_STOP_CM, pivot seul après AVOID_BACK_MAX_MS, hystérésis
    US_CLEAR_CM) et sa tête balaie ±HEAD_BALANCE_SWEEP_DEG en équilibre ; le simulateur
    décrivait encore le robot d'avant. Il en est maintenant le miroir :
    - sim/balancebot_sim.py (référence) puis sim/web/engine.js, ligne à ligne : la
    couche DÉPLACEMENT de balance.cpp que les moteurs n'avaient pas — consignes
    cmdForward / cmdTurn bornées et lissées (kCmdSlewPerS), plafond / recul imp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
